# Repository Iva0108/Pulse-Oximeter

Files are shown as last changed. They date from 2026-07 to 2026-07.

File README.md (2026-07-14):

A pulse oximeter project that consists of hardware, firmware, and software implementation. This project is provided for educational and research purposes only, 
and is NOT authorized for medical use.
This project presents a portable pulse oximeter capable of measuring blood oxygen saturation (SpO₂) and heart rate (BPM) using the MAX30102
sensor. The measured values are displayed on an OLED screen and transmitted wirelessly to an Android application via an HC-05 Bluetooth module.

Features:
- Measurement of SpO₂ (oxygen saturation)
- Measurement of heart rate (BPM)
- Real-time display on SSD1306 OLED (128×64)
- Wireless Bluetooth communication
- Custom KiCad PCB design
- Android application for data visualization
- Powered by a 3.7 V Li-Po battery with charging circuitry

Building the Project:

Android App
The Android application was developed in Java using Android Studio. 
It connects to the HC-05 module via Bluetooth SPP and displays the received BPM and SpO₂ values in real time.
Expected data format:
BPM:72,SPO2:98
- Open Oximeter_App/PulseOxApp in Android Studio.
- Allow Gradle synchronization.
- Build and run the application.

Firmware
The firmware was developed in the Arduino IDE for the STM32 Blue Pill. 
It uses the MAX30105 library to acquire sensor data, calculate heart rate and oxygen saturation, and transmit the values over Bluetooth.
- Open BT_PulseOximeter.ino in the Arduino IDE.
- Select the STM32 board package (if not already installed, install it via Boards Manager).
- Upload the firmware using ST-Link. It might be necessary to use ST Programmer for flashing instead of doing it directly in Arduino IDE, in which case you will need
to select either a .bin or .elf file to do so.

PCB
The custom PCB was designed in KiCad as a two-layer board with separate schematic sheets for power supply, MCU, sensor module, HC-05 Bluetooth module and OLED display.
- Open Oximeter.kicad_pro in KiCad.
- Use the PCB editor or 3D viewer to inspect the design.

Hardware & Firmware:

oxi3

Android App:

oxi4

PCB:



Case:



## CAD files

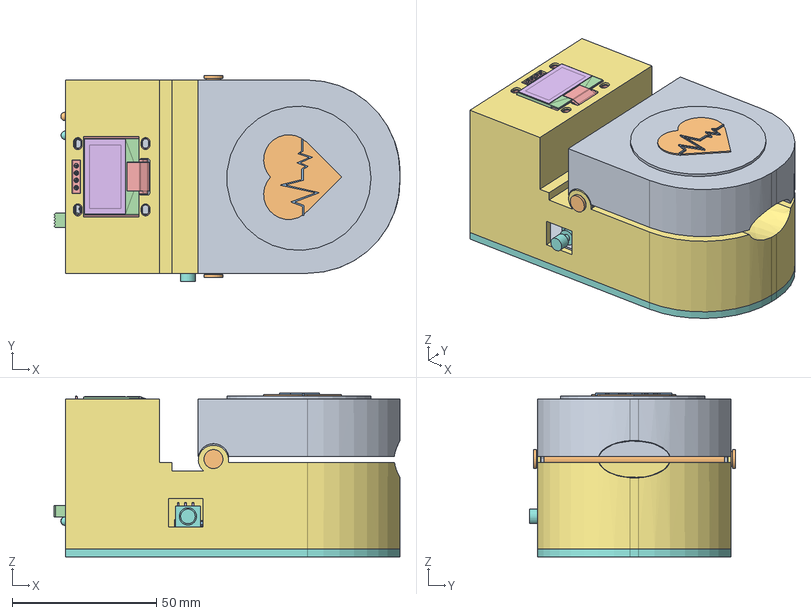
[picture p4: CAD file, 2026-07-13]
OximeterCase/OximeterCase/OximeterCase.FCStd
120.0 x 71.3 x 56.8 mm
ROD Fusion001
SOT-225
B2B-PH-K004
B2B-PH-K005
B2B-PH-K006
R_0805_2012Metric018
LED_D3.0mm_Horizontal_O1.27mm_Z2.0mm_Clear001
R_0805_2012Metric019
C_1206_3216Metric024
C_1206_3216Metric025
R_0805_2012Metric020
PinSocket_1x04_P2.54mm_Vertical001
SOIC-8-1EP_3.9x4.9mm_P1.27mm_EP2.29x3mm001
Crystal_SMD_HC49-SD001
C_1206_3216Metric026
R_0805_2012Metric021
C_1206_3216Metric027
R_0805_2012Metric022
D_SMA001
C_1206_3216Metric028
C_1206_3216Metric029
SOT-226
C_1206_3216Metric030
R_0805_2012Metric023
C_1206_3216Metric031
SW_E-Switch_EG1224_SPDT_Angled001
R_0805_2012Metric024
C_1206_3216Metric032
C_1206_3216Metric033
R_0805_2012Metric025
C_1206_3216Metric034
R_0805_2012Metric026
HC-043
HC-044
HC-045
HC-046
HC-047
HC-048
HC-049
HC-050
HC-051
HC-052
HC-053
HC-054
HC-055
HC-056
HC-057
HC-058
HC-059
HC-060
HC-061
HC-062
HC-063
HC-064
HC-065
HC-066
HC-067
HC-068
HC-069
HC-070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

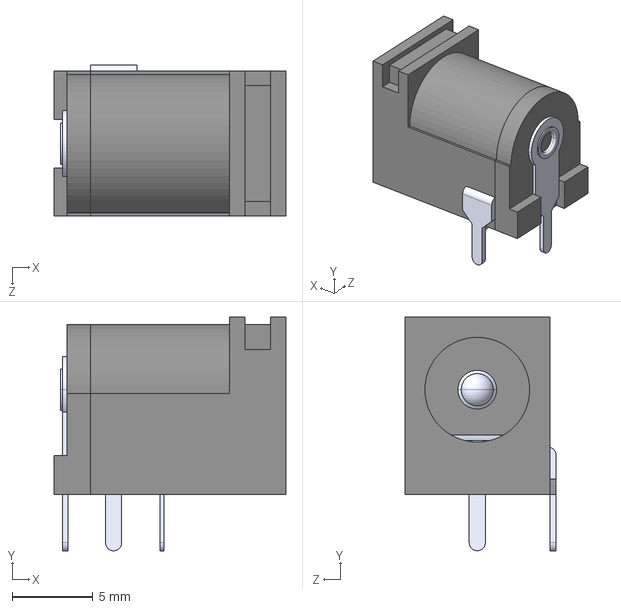
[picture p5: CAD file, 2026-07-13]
OximeterCase/OximeterCase/PJ 102A/PJ-102A.step
14.4 x 14.5 x 9.40 mm

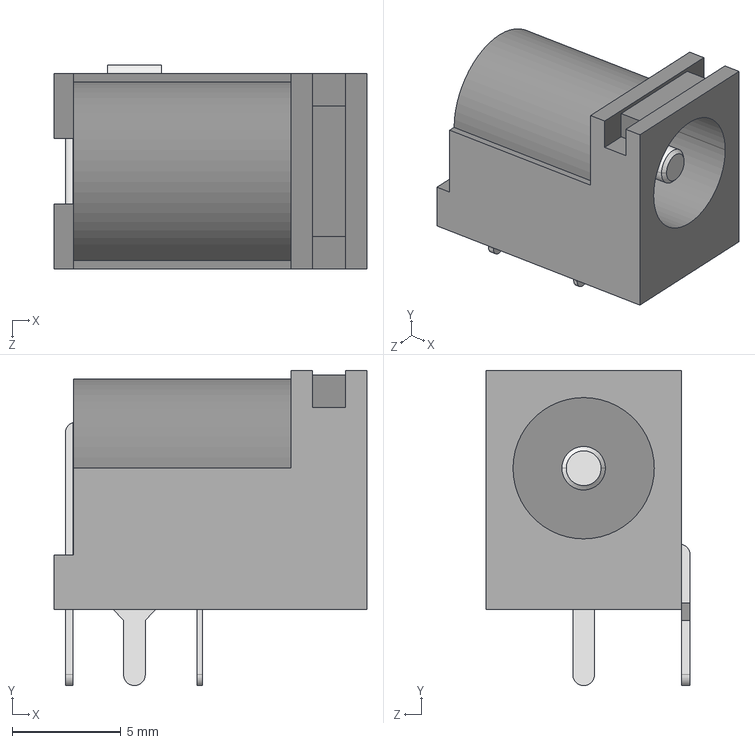
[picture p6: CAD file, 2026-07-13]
OximeterCase/OximeterCase/PJ 102A/PJ-102A--3DModel-STEP-1.STEP
14.4 x 14.5 x 9.40 mm

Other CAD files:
OximeterCase/OximeterCase/Unnamed.FCStd

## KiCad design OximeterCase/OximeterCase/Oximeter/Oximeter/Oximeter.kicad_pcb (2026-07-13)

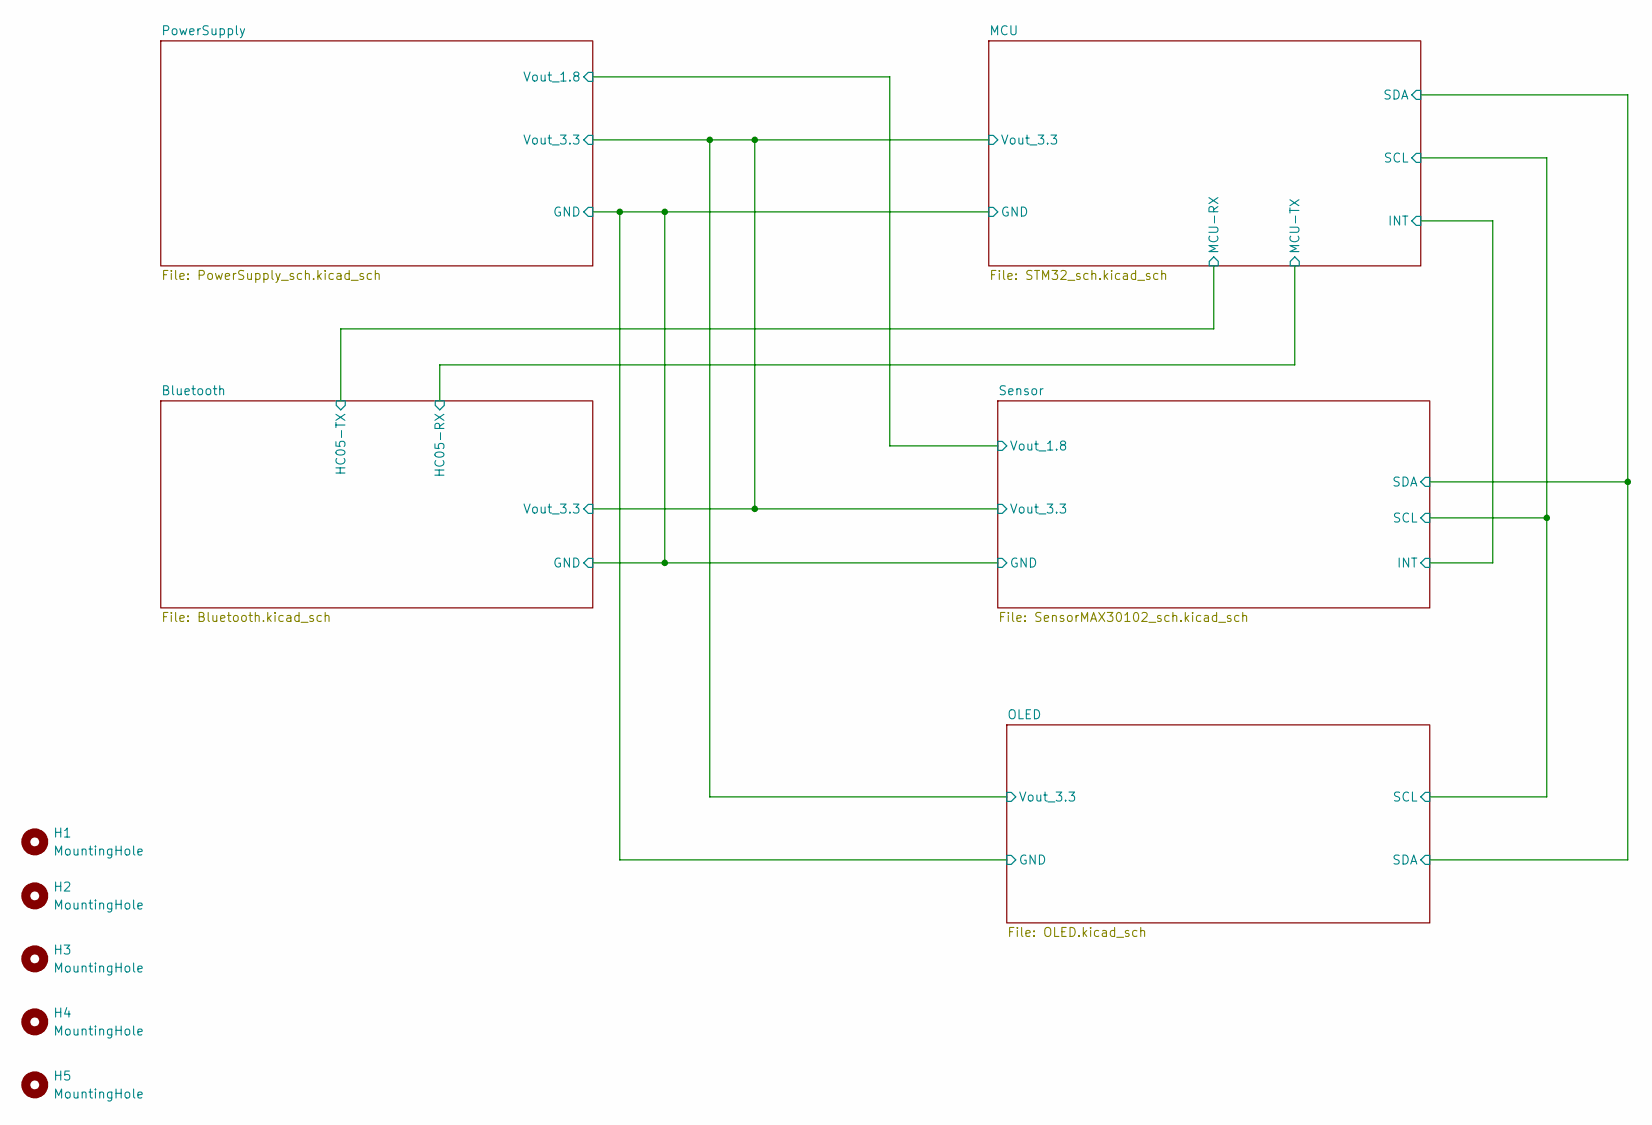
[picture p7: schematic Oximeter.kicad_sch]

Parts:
H1, H2, H3, H4, H5: MountingHole; MountingHole_2.2mm_M2

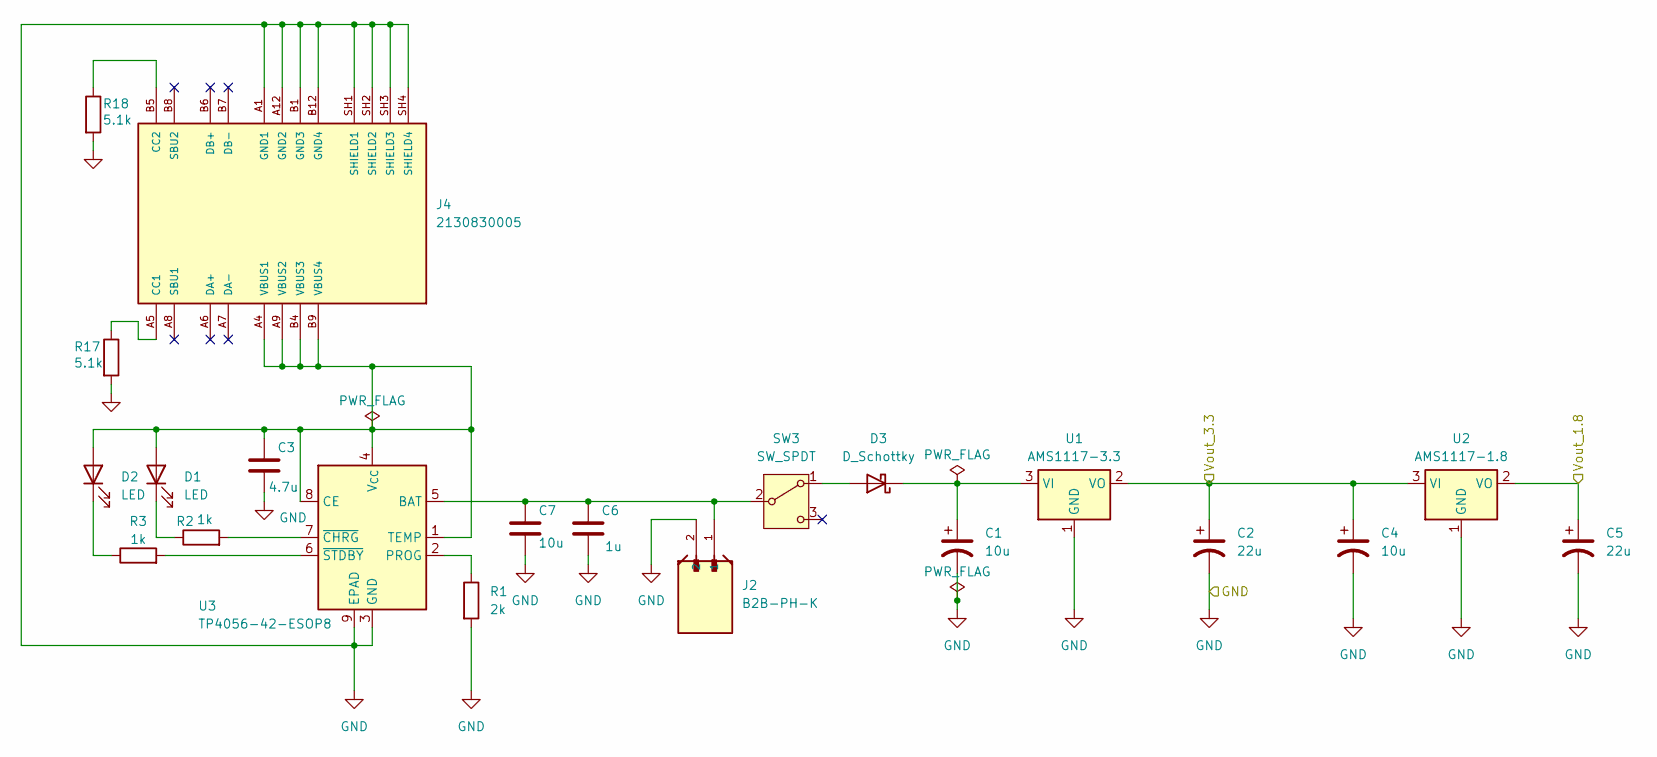
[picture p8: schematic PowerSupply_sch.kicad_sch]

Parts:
C1, C4, C7: 10u; C_1206_3216Metric_Pad1.33x1.80mm_HandSolder
C2, C5: 22u; C_1206_3216Metric_Pad1.33x1.80mm_HandSolder
C3: 4.7u; C_1206_3216Metric_Pad1.33x1.80mm_HandSolder
C6: 1u; C_1206_3216Metric_Pad1.33x1.80mm_HandSolder
D1: LED; LED_D3.0mm_Horizontal_O1.27mm_Z2.0mm
D2: LED; LED_D3.0mm_Horizontal_O1.27mm_Z2.0mm_Clear
D3: D_Schottky; D_SMA
J2: B2B-PH-K; JST_B2B-PH-K
J4: 2130830005; MOLEX_2130830005; PARTREV A1
R1: 2k; R_0805_2012Metric
R2, R3: 1k; R_0805_2012Metric
R17, R18: 5.1k; R_0805_2012Metric
SW3: SW_SPDT; SW_E-Switch_EG1224_SPDT_Angled
U1: AMS1117-3.3; SOT-223-3_TabPin2
U2: AMS1117-1.8; SOT-223-3_TabPin2
U3: TP4056-42-ESOP8; SOIC-8-1EP_3.9x4.9mm_P1.27mm_EP2.41x3.3mm_ThermalVias

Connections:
GND: C1.2, C2.2, C3.2, C4.2, C5.2, C6.2, C7.2, J2.2, J4.A1 (GND1), J4.A12 (GND2), J4.B1 (GND3), J4.B12 (GND4), J4.SH1 (SHIELD1), J4.SH2 (SHIELD2), J4.SH3 (SHIELD3), J4.SH4 (SHIELD4), R1.2, R17.2, R18.2, U1.1 (GND), U2.1 (GND), U3.3 (GND), U3.9 (EPAD); also elsewhere on the board
unnamed: C3.1, D1.2 (A), D2.2 (A), J4.A4 (VBUS1), J4.A9 (VBUS2), J4.B4 (VBUS3), J4.B9 (VBUS4), U3.1 (TEMP), U3.4 (V_{CC}), U3.8 (CE)
unnamed: D1.1 (K), R2.1
unnamed: D2.1 (K), R3.1
unnamed: D3.2 (A), SW3.1 (A)
unnamed: C1.1, D3.1 (K), U1.3 (VI)
unnamed: J4.A5 (CC1), R17.1
unnamed: J4.B5 (CC2), R18.1
unnamed: C6.1, C7.1, J2.1, SW3.2 (B), U3.5 (BAT)
unnamed: R1.1, U3.2 (PROG)
unnamed: R2.2, U3.7 (~CHRG)
unnamed: R3.2, U3.6 (~STDBY)
VLED+: C5.1, U2.2 (VO); also elsewhere on the board
Vout_3.3: C2.1, C4.1, U1.2 (VO), U2.3 (VI); also elsewhere on the board

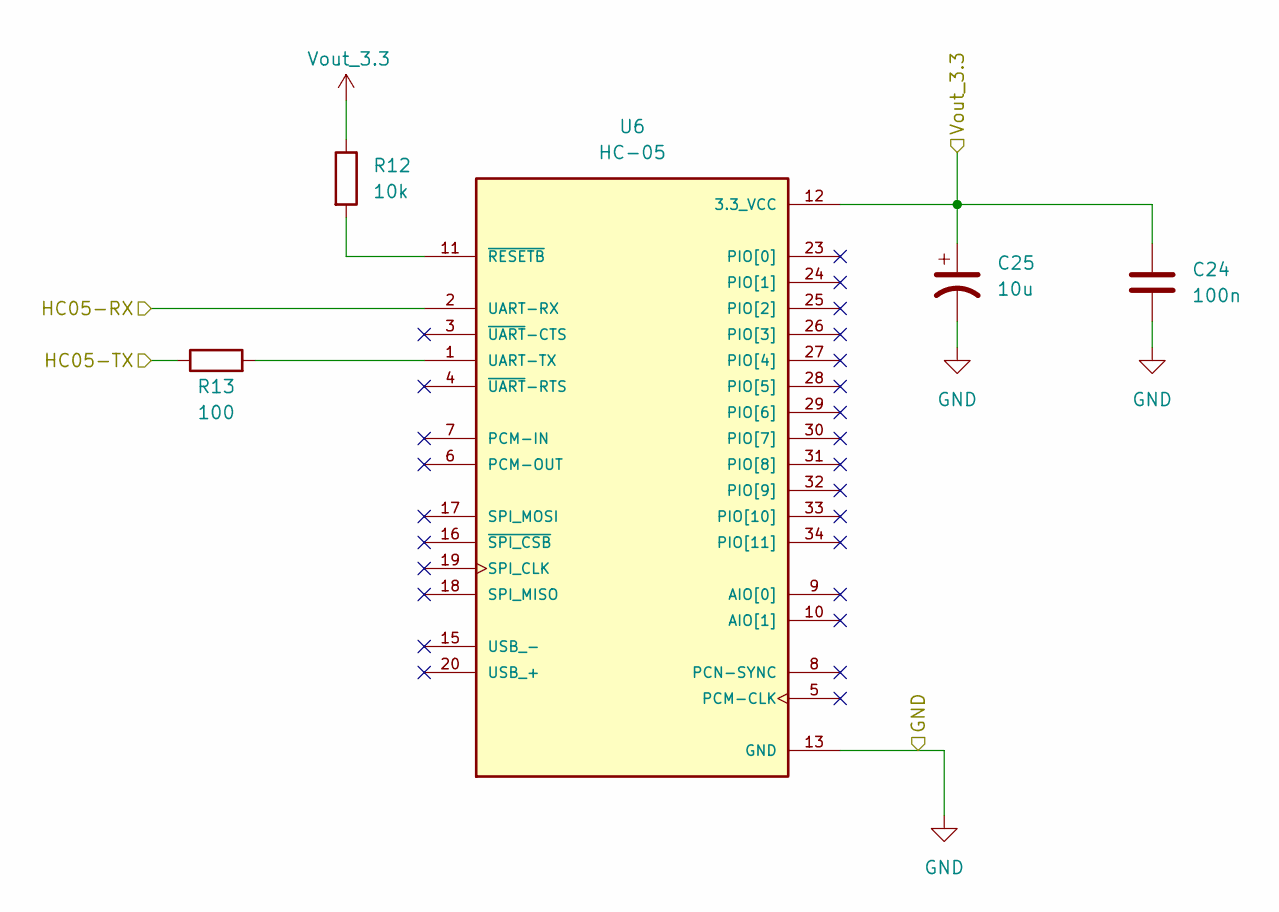
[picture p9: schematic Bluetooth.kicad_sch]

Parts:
C24: 100n; C_1206_3216Metric_Pad1.33x1.80mm_HandSolder
C25: 10u; C_1206_3216Metric_Pad1.33x1.80mm_HandSolder
R12: 10k; R_0805_2012Metric
R13: 100; R_0805_2012Metric
U6: HC-05; XCVR_HC-05; PARTREV v1.0

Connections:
/Bluetooth/HC05-RX: U6.2 (UART-RX); also elsewhere on the board
/Bluetooth/HC05-TX: R13.1; also elsewhere on the board
GND: C24.2, C25.2, U6.13 (GND), U6.21 (GND), U6.22 (GND); also elsewhere on the board
unnamed: R13.2, U6.1 (UART-TX)
unnamed: R12.2, U6.11 (~RESETB)
Vout_3.3: C24.1, C25.1, R12.1, U6.12 (3.3_VCC); also elsewhere on the board

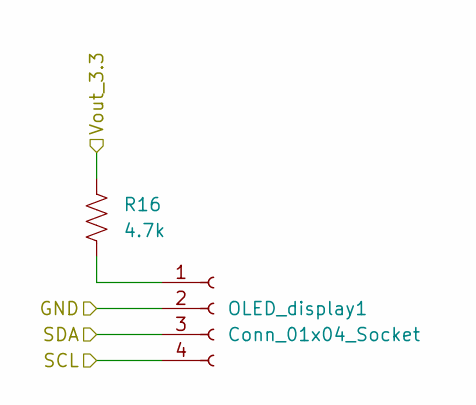
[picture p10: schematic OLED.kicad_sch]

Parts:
OLED_display1: Conn_01x04_Socket; PinSocket_1x04_P2.54mm_Vertical
R16: 4.7k; R_0805_2012Metric

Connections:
/MCU/SCL: OLED_display1.4; also elsewhere on the board
/MCU/SDA: OLED_display1.3; also elsewhere on the board
GND: OLED_display1.2; also elsewhere on the board
unnamed: OLED_display1.1, R16.2
Vout_3.3: R16.1; also elsewhere on the board

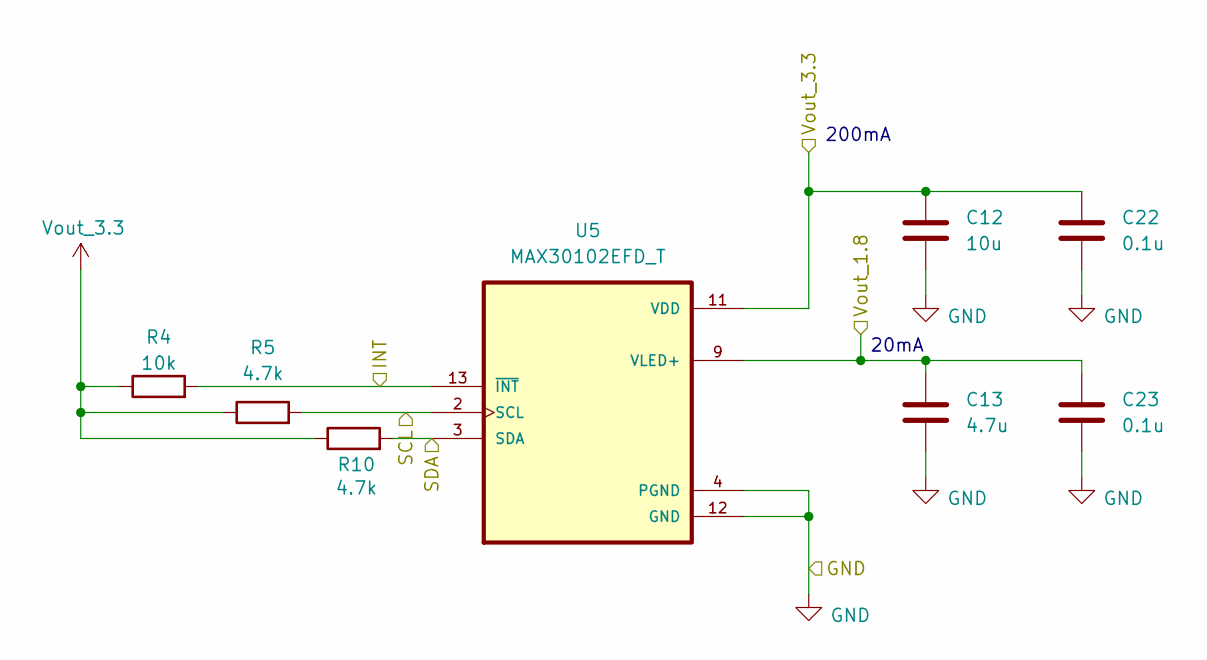
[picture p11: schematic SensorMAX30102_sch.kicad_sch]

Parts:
C12: 10u; C_1206_3216Metric_Pad1.33x1.80mm_HandSolder
C13: 4.7u; C_1206_3216Metric_Pad1.33x1.80mm_HandSolder
C22, C23: 0.1u; C_1206_3216Metric_Pad1.33x1.80mm_HandSolder
R4: 10k; R_0805_2012Metric
R5, R10: 4.7k; R_0805_2012Metric
U5: MAX30102EFD_T; XDCR_MAX30101EFD_

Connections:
/MCU/INT: R4.2, U5.13 (~INT); also elsewhere on the board
/MCU/SCL: R5.2, U5.2 (SCL); also elsewhere on the board
/MCU/SDA: R10.2, U5.3 (SDA); also elsewhere on the board
GND: C12.2, C13.2, C22.2, C23.2, U5.4 (PGND), U5.12 (GND); also elsewhere on the board
VLED+: C13.1, C23.1, U5.9 (VLED+), U5.10 (VLED+); also elsewhere on the board
Vout_3.3: C12.1, C22.1, R4.1, R5.1, R10.1, U5.11 (VDD); also elsewhere on the board

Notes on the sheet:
200mA
20mA

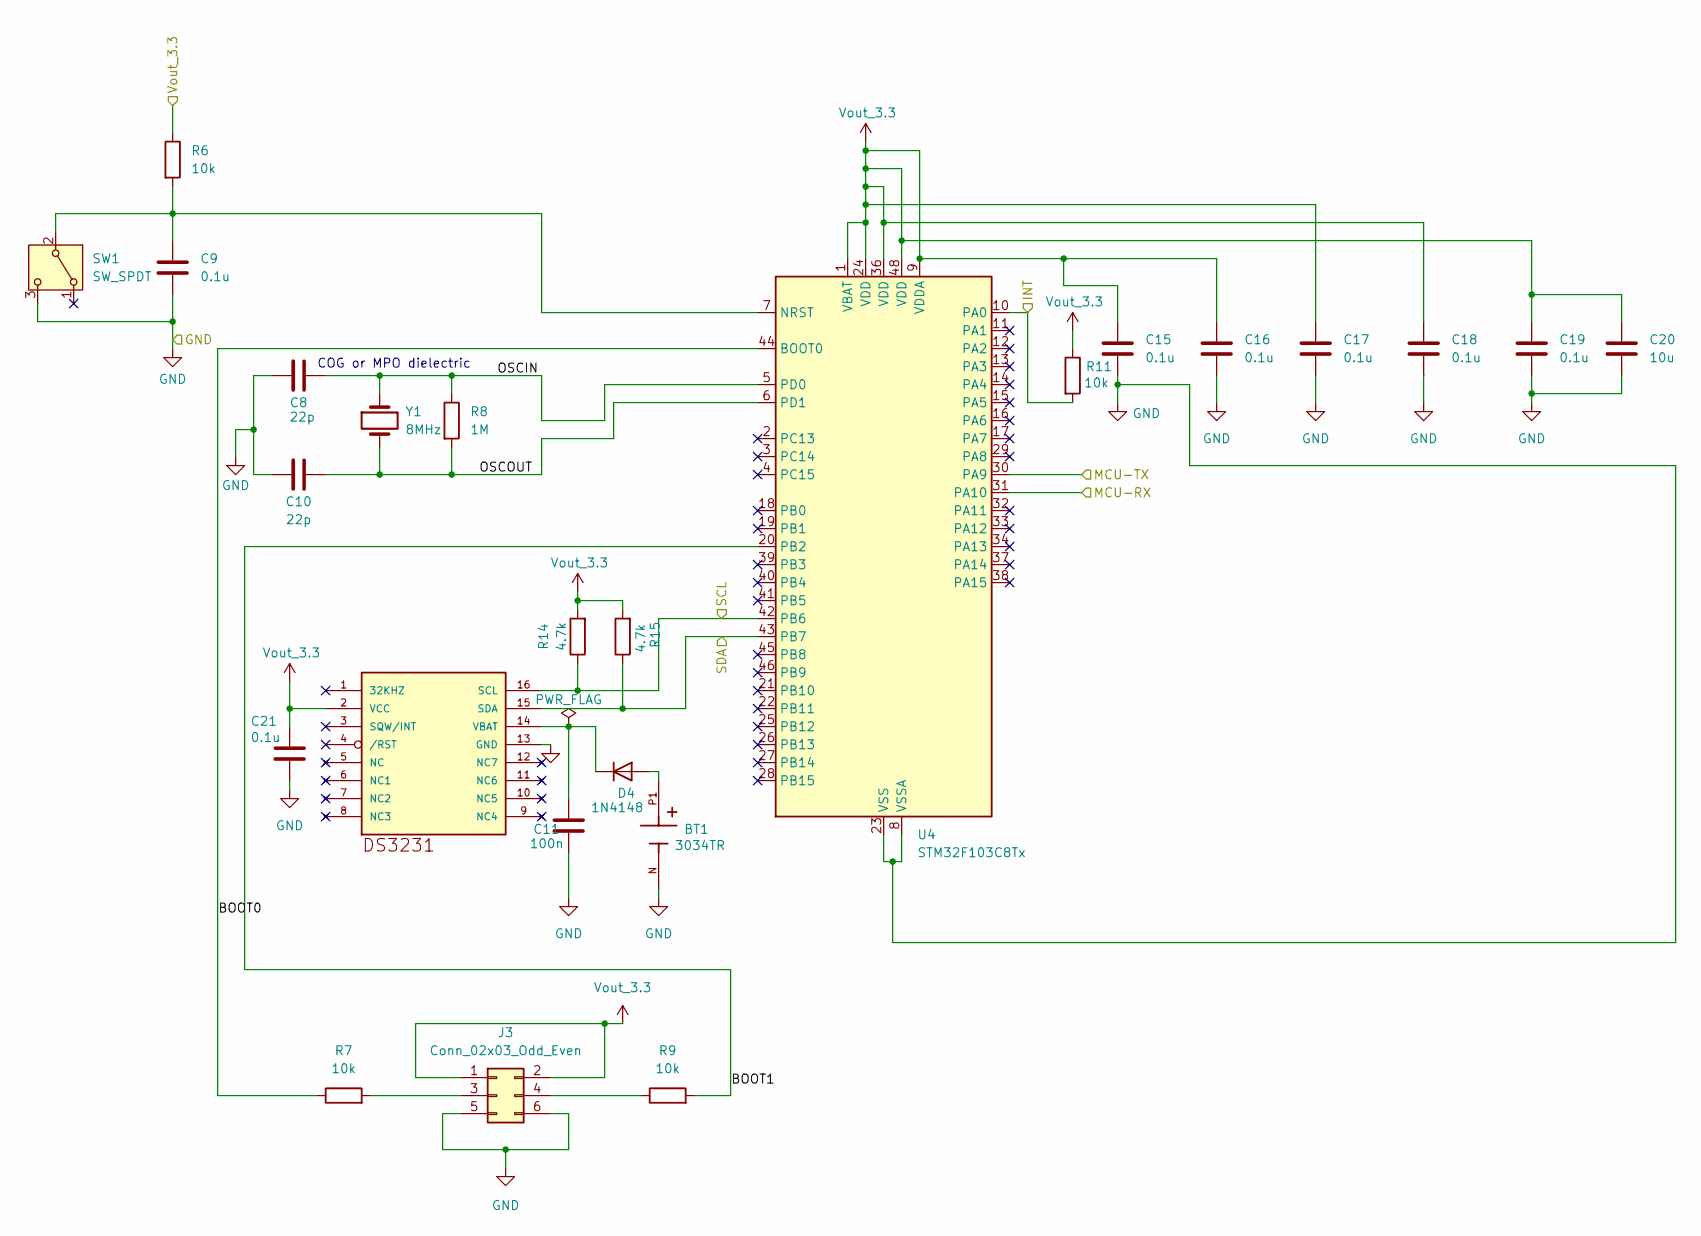
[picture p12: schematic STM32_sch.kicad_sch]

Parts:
BT1: 3034TR; BAT_3034TR; PARTREV E
C8, C10: 22p; C_1206_3216Metric_Pad1.33x1.80mm_HandSolder
C9, C15, C16, C17, C18, C19, C21: 0.1u; C_1206_3216Metric_Pad1.33x1.80mm_HandSolder
C11: 100n; C_1206_3216Metric_Pad1.33x1.80mm_HandSolder
C20: 10u; C_1206_3216Metric_Pad1.33x1.80mm_HandSolder
D4: 1N4148; D_DO-35_SOD27_P7.62mm_Horizontal
IC2: DS3231; SO16W
J3: Conn_02x03_Odd_Even; PinHeader_2x03_P2.54mm_Vertical
R6, R7, R9, R11: 10k; R_0805_2012Metric
R8: 1M; R_0805_2012Metric
R14, R15: 4.7k; R_0805_2012Metric
SW1: SW_SPDT; SW_NKK_BB15AH
U4: STM32F103C8Tx; LQFP-48_7x7mm_P0.5mm
Y1: 8MHz; Crystal_SMD_HC49-SD

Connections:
/Bluetooth/HC05-RX: U4.30 (PA9); also elsewhere on the board
/Bluetooth/HC05-TX: U4.31 (PA10); also elsewhere on the board
/MCU/BOOT0: R7.1, U4.44 (BOOT0)
/MCU/BOOT1: R9.2, U4.20 (PB2)
/MCU/INT: R11.2, U4.10 (PA0); also elsewhere on the board
/MCU/OSCIN: C8.2, R8.1, U4.5 (PD0), Y1.1
/MCU/OSCOUT: C10.2, R8.2, U4.6 (PD1), Y1.2
/MCU/SCL: IC2.16 (SCL), R14.1, U4.42 (PB6); also elsewhere on the board
/MCU/SDA: IC2.15 (SDA), R15.1, U4.43 (PB7); also elsewhere on the board
GND: BT1.N, C8.1, C9.2, C10.1, C11.2, C15.2, C16.2, C17.2, C18.2, C19.2, C20.2, C21.2, IC2.13 (GND), J3.5, J3.6, SW1.3 (C), U4.8 (VSSA), U4.23 (VSS), U4.35 (VSS), U4.47 (VSS); also elsewhere on the board
unnamed: BT1.P1, BT1.P2, D4.2 (A)
unnamed: C11.1, D4.1 (K), IC2.14 (VBAT)
unnamed: J3.3, R7.2
unnamed: J3.4, R9.1
unnamed: C9.1, R6.2, SW1.2 (B), U4.7 (NRST)
Vout_3.3: C15.1, C16.1, C17.1, C18.1, C19.1, C20.1, C21.1, IC2.2 (VCC), J3.1, J3.2, R6.1, R11.1, R14.2, R15.2, U4.1 (VBAT), U4.9 (VDDA), U4.24 (VDD), U4.36 (VDD), U4.48 (VDD); also elsewhere on the board

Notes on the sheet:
COG or MPO dielectric

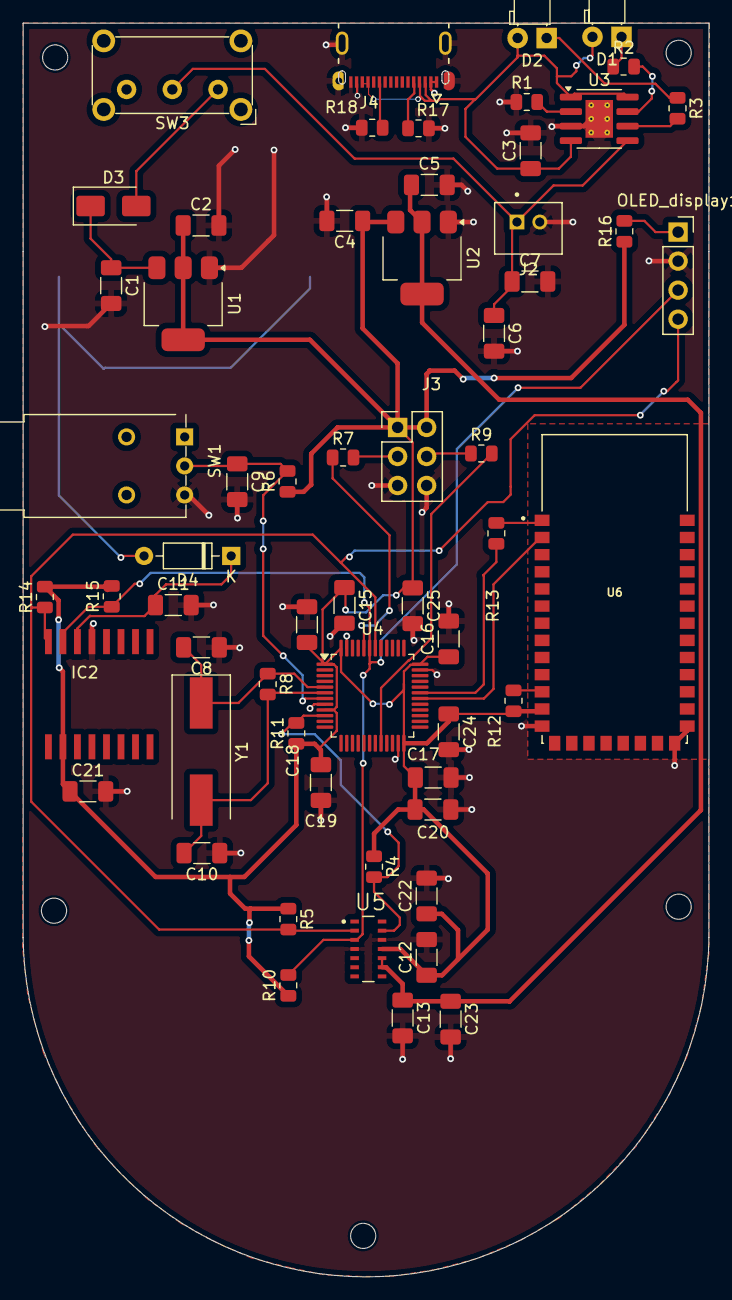
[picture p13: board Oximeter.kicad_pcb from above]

Board: 2 copper layers, 60.0 x 109.7 mm, 66 parts (1 on the bottom side), 31 nets.

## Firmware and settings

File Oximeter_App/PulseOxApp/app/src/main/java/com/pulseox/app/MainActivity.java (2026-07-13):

package com.pulseox.app;

import android.Manifest;
import android.bluetooth.BluetoothAdapter;
import android.bluetooth.BluetoothDevice;
import android.content.Intent;
import android.content.pm.PackageManager;
import android.os.Build;
import android.os.Bundle;
import android.os.Handler;
import android.os.Looper;
import android.view.View;
import android.widget.*;
import androidx.annotation.NonNull;
import androidx.appcompat.app.AppCompatActivity;
import androidx.core.app.ActivityCompat;
import androidx.core.content.ContextCompat;

import java.util.ArrayList;
import java.util.List;
import java.util.Set;
import android.annotation.SuppressLint;

@SuppressLint("MissingPermission")
public class MainActivity extends AppCompatActivity {

    private static final int REQUEST_ENABLE_BT  = 1;
    private static final int REQUEST_PERMISSIONS = 2;

    // UI
    private Spinner  spinnerDevices;
    private Button   btnConnect, btnDisconnect;
    private TextView tvBpm, tvSpo2, tvStatus, tvLog;
    private ScrollView scrollLog;

    // BT
    private BluetoothAdapter  btAdapter;
    private BluetoothService  btService;
    private List<BluetoothDevice> pairedDevices = new ArrayList<>();

    // Handler runs on Main thread — safe to touch UI
    private final Handler handler = new Handler(Looper.getMainLooper()) {
        @Override
        public void handleMessage(@NonNull android.os.Message msg) {
            switch (msg.what) {
                case BluetoothService.MSG_CONNECTED:
                    setStatus("Connected ✓", "#27AE60");
                    btnConnect.setEnabled(false);
                    btnDisconnect.setEnabled(true);
                    appendLog("Connected to device.");
                    break;

                case BluetoothService.MSG_CONNECTION_FAIL:
                    setStatus("Connection failed ✗", "#E74C3C");
                    btnConnect.setEnabled(true);
                    btnDisconnect.setEnabled(false);
                    appendLog("Connection failed: " + msg.obj);
                    break;

                case BluetoothService.MSG_DATA_RECEIVED:
                    String raw = (String) msg.obj;
                    appendLog("RX: " + raw);
                    DataParser.Reading r = DataParser.parse(raw);
                    if (r.valid) {
                        tvBpm.setText(String.valueOf(r.bpm));
                        tvSpo2.setText(r.spo2 + "%");
                        colorSpo2(r.spo2);
                    } else {
                        appendLog("⚠ Could not parse: " + raw);
                    }
                    break;

                case BluetoothService.MSG_DISCONNECTED:
                    setStatus("Disconnected", "#7F8C8D");
                    btnConnect.setEnabled(true);
                    btnDisconnect.setEnabled(false);
                    tvBpm.setText("--");
                    tvSpo2.setText("--%");
                    appendLog("Disconnected.");
                    break;
            }
        }
    };

    // ── Lifecycle ─────────────────────────────────────────────────────────────

    @Override
    protected void onCreate(Bundle savedInstanceState) {
        super.onCreate(savedInstanceState);
        setContentView(R.layout.activity_main);

        // Bind views
        spinnerDevices  = findViewById(R.id.spinnerDevices);
        btnConnect      = findViewById(R.id.btnConnect);
        btnDisconnect   = findViewById(R.id.btnDisconnect);
        tvBpm           = findViewById(R.id.tvBpm);
        tvSpo2          = findViewById(R.id.tvSpo2);
        tvStatus        = findViewById(R.id.tvStatus);
        tvLog           = findViewById(R.id.tvLog);
        scrollLog       = findViewById(R.id.scrollLog);

        btAdapter = BluetoothAdapter.getDefaultAdapter();

        if (btAdapter == null) {
            Toast.makeText(this, "Bluetooth not supported on this device", Toast.LENGTH_LONG).show();
            finish();
            return;
        }

        btService = new BluetoothService(handler);

        btnConnect.setOnClickListener(v -> connectToSelected());
        btnDisconnect.setOnClickListener(v -> {
            btService.disconnect();
        });

        requestPermissionsIfNeeded();
    }

    @Override
    protected void onDestroy() {
        super.onDestroy();
        if (btService != null) btService.disconnect();
    }

    // ── Permissions ───────────────────────────────────────────────────────────

    private void requestPermissionsIfNeeded() {
        List<String> needed = new ArrayList<>();

        if (Build.VERSION.SDK_INT >= Build.VERSION_CODES.S) {
            // Android 12+
            if (ContextCompat.checkSelfPermission(this,
                    Manifest.permission.BLUETOOTH_CONNECT) != PackageManager.PERMISSION_GRANTED) {
                needed.add(Manifest.permission.BLUETOOTH_CONNECT);
            }
            if (ContextCompat.checkSelfPermission(this,
                    Manifest.permission.BLUETOOTH_SCAN) != PackageManager.PERMISSION_GRANTED) {
                needed.add(Manifest.permission.BLUETOOTH_SCAN);
            }
        } else {
            // Android 6–11
            if (ContextCompat.checkSelfPermission(this,
                    Manifest.permission.ACCESS_FINE_LOCATION) != PackageManager.PERMISSION_GRANTED) {
                needed.add(Manifest.permission.ACCESS_FINE_LOCATION);
            }
        }

        if (!needed.isEmpty()) {
            ActivityCompat.requestPermissions(this,
                    needed.toArray(new String[0]), REQUEST_PERMISSIONS);
        } else {
            initBluetooth();
        }
    }

    @Override
    public void onRequestPermissionsResult(int requestCode,
                                           @NonNull String[] permissions, @NonNull int[] grantResults) {
        super.onRequestPermissionsResult(requestCode, permissions, grantResults);
        if (requestCode == REQUEST_PERMISSIONS) {
            boolean allGranted = true;
            for (int r : grantResults) {
                if (r != PackageManager.PERMISSION_GRANTED) { allGranted = false; break; }
            }
            if (allGranted) {
                initBluetooth();
            } else {
                Toast.makeText(this,
                        "Bluetooth permissions are required for this app.",
                        Toast.LENGTH_LONG).show();
            }
        }
    }

    // ── Bluetooth Init ────────────────────────────────────────────────────────

    private void initBluetooth() {
        if (!btAdapter.isEnabled()) {
            Intent enableBtIntent = new Intent(BluetoothAdapter.ACTION_REQUEST_ENABLE);
            startActivityForResult(enableBtIntent, REQUEST_ENABLE_BT);
        } else {
            populateDeviceSpinner();
        }
    }

    @Override
    protected void onActivityResult(int requestCode, int resultCode, Intent data) {
        super.onActivityResult(requestCode, resultCode, data);
        if (requestCode == REQUEST_ENABLE_BT) {
            if (resultCode == RESULT_OK) {
                populateDeviceSpinner();
            } else {
                Toast.makeText(this, "Bluetooth must be enabled.", Toast.LENGTH_LONG).show();
            }
        }
    }

    private void populateDeviceSpinner() {
        Set<BluetoothDevice> bonded = btAdapter.getBondedDevices();
        pairedDevices.clear();
        List<String> names = new ArrayList<>();

        for (BluetoothDevice d : bonded) {
            pairedDevices.add(d);
            names.add(d.getName() + "\n" + d.getAddress());
        }

        if (names.isEmpty()) {
            Toast.makeText(this,
                    "No paired devices found. Pair HC-05 in Android Bluetooth settings first.",
                    Toast.LENGTH_LONG).show();
            return;
        }

        ArrayAdapter<String> adapter = new ArrayAdapter<>(this,
                android.R.layout.simple_spinner_item, names);
        adapter.setDropDownViewResource(android.R.layout.simple_spinner_dropdown_item);
        spinnerDevices.setAdapter(adapter);
        appendLog("Found " + names.size() + " paired device(s).");
    }

    // ── Connect ───────────────────────────────────────────────────────────────

    private void connectToSelected() {
        int idx = spinnerDevices.getSelectedItemPosition();
        if (idx < 0 || idx >= pairedDevices.size()) {
            Toast.makeText(this, "Select a device first.", Toast.LENGTH_SHORT).show();
            return;
        }
        BluetoothDevice device = pairedDevices.get(idx);
        setStatus("Connecting…", "#F39C12");
        btnConnect.setEnabled(false);
        appendLog("Connecting to " + device.getName() + "…");
        btService.connect(device);
    }

    // ── UI Helpers ────────────────────────────────────────────────────────────

    private void setStatus(String text, String hexColor) {
        tvStatus.setText(text);
        tvStatus.setTextColor(android.graphics.Color.parseColor(hexColor));
    }

    private void colorSpo2(int spo2) {
        if (spo2 >= 95) {
            tvSpo2.setTextColor(android.graphics.Color.parseColor("#27AE60")); // Green
        } else if (spo2 >= 90) {
            tvSpo2.setTextColor(android.graphics.Color.parseColor("#F39C12")); // Orange
        } else {
            tvSpo2.setTextColor(android.graphics.Color.parseColor("#E74C3C")); // Red — hypoxia warning
        }
    }

    private void appendLog(String msg) {
        tvLog.append(msg + "\n");
        scrollLog.post(() -> scrollLog.fullScroll(View.FOCUS_DOWN));
    }
}

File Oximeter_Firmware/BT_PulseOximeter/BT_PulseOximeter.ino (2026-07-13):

#include <Wire.h>
#include <Adafruit_GFX.h>
#include <Adafruit_SSD1306.h>

#include "MAX30105.h"
#include "heartRate.h"
#include "spo2_algorithm.h"

// ---------------- OLED SETTINGS ----------------
#define SCREEN_WIDTH 128
#define SCREEN_HEIGHT 64
#define OLED_RESET -1

Adafruit_SSD1306 display(SCREEN_WIDTH, SCREEN_HEIGHT, &Wire, OLED_RESET);

// ---------------- MAX30102 ----------------
MAX30105 particleSensor;

#if defined(__AVR_ATmega328P__) || defined(__AVR_ATmega168__)
uint16_t irBuffer[100];
uint16_t redBuffer[100];
#else
uint32_t irBuffer[100];
uint32_t redBuffer[100];
#endif

int32_t  spo2;
int8_t   validSPO2;
int32_t  heartRate;
int8_t   validHeartRate;

unsigned long lastUpdate = 0;

// -----------------------------------------------
// HC-05 is on Serial2: PA2 = TX,  PA3 = RX
// HC-05 default baud rate is 9600
// -----------------------------------------------
#define BT_SERIAL Serial2
#define BT_BAUD   9600
HardwareSerial Serial2(PA3, PA2);
void setup()
{
  Serial.begin(115200);

  // ── Bluetooth UART ──────────────────────────────
  BT_SERIAL.begin(BT_BAUD);
  Serial.println("HC-05 serial started on Serial2 (PA2/PA3) at 9600");

  // -------- OLED INIT --------
  if (!display.begin(SSD1306_SWITCHCAPVCC, 0x3C))
  {
    Serial.println("SSD1306 failed");
    while (1);
  }

  display.clearDisplay();
  display.setTextColor(SSD1306_WHITE);

  display.setTextSize(2);
  display.setCursor(10, 10);
  display.println("MAX30102");

  display.setTextSize(1);
  display.setCursor(18, 40);
  display.println("Initializing...");
  display.display();

  // -------- SENSOR INIT --------
  if (!particleSensor.begin(Wire, I2C_SPEED_STANDARD))
  {
    Serial.println("MAX30102 not found");

    display.clearDisplay();
    display.setTextSize(1);
    display.setCursor(0, 20);
    display.println("MAX30102");
    display.println("NOT FOUND");
    display.display();

    while (1);
  }

  particleSensor.setup(
    50,    // LED brightness
    8,     // sample average
    2,     // LED mode
    50,    // sample rate
    411,   // pulse width
    4096   // ADC range
  );

  display.clearDisplay();
  display.setTextSize(1);
  display.setCursor(0, 20);
  display.println("Place finger");
  display.println("on sensor");
  display.display();

  delay(2000);
}

void loop()
{
  // Collect 100 samples
  for (byte i = 0; i < 100; i++)
  {
    while (!particleSensor.available())
      particleSensor.check();

    redBuffer[i] = particleSensor.getRed();
    irBuffer[i]  = particleSensor.getIR();

    particleSensor.nextSample();
  }

  // Calculate HR and SpO2
  maxim_heart_rate_and_oxygen_saturation(
    irBuffer,
    100,
    redBuffer,
    &spo2,
    &validSPO2,
    &heartRate,
    &validHeartRate
  );

  // Update every second
  if (millis() - lastUpdate > 1000)
  {
    lastUpdate = millis();

    // ── BLUETOOTH OUTPUT ─────────────────────────────────────────────────────
    // Format: "BPM:72,SPO2:98\n" (what DataParser.java expects).
    // Only send when BOTH readings are valid; otherwise send zeroes
    // so the app can show "--" instead of stale data.
    if (validHeartRate && validSPO2)
    {
      BT_SERIAL.print("BPM:");
      BT_SERIAL.print((int)heartRate);
      BT_SERIAL.print(",SPO2:");
      BT_SERIAL.print((int)spo2);
      BT_SERIAL.print("\n");   
    }
    else
    {
      // Send zeroes — DataParser will mark them invalid and the app shows "--"
      BT_SERIAL.print("BPM:0,SPO2:0\n");
    }

    // ── USB/DEBUG OUTPUT (for Serial Monitor) ─────────────────────
    Serial.print("HR: ");
    if (validHeartRate) Serial.print(heartRate);
    else                Serial.print("Invalid");

    Serial.print(" BPM | SpO2: ");
    if (validSPO2) { Serial.print(spo2); Serial.println("%"); }
    else             Serial.println("Invalid");

    // -------- OLED OUTPUT --------
    display.clearDisplay();

    display.setTextSize(1);
    display.setCursor(0, 0);
    display.println("Pulse Oximeter");

    display.setTextSize(2);
    display.setCursor(0, 18);
    if (validHeartRate) 
    { display.print(heartRate); display.println(" BPM");
    }
    else                  
      display.println("HR --");

    display.setCursor(0, 45);
    if (validSPO2) 
    { display.print(spo2); display.println("%"); 
    }
    else             
      display.println("SpO2 --");

    display.display();
  }
}
